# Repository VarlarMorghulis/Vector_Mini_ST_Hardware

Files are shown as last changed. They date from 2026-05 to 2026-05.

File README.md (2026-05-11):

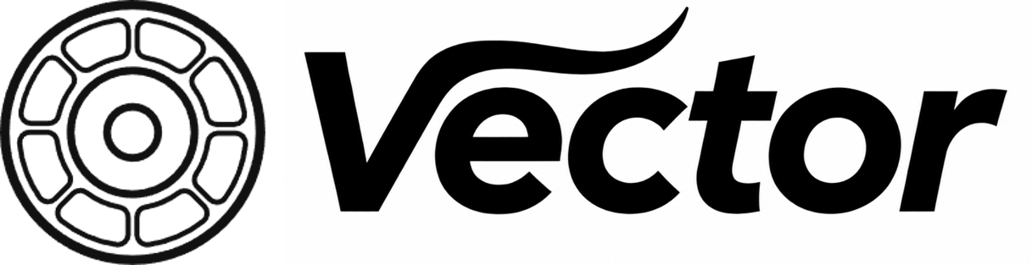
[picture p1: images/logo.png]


## 功能介绍

        Vector 驱动器是一款中小型尺寸，基于矢量控制的永磁同步电机驱动，适用于轮毂电机，关节电机等。24V母线电压下，实测最高支持约400W的持续功率输入（需散热片）。内部算法可实现基础的电流，速度，位置闭环，同时具有一定的参数辨识能力。目前仅支持有感运行，板载了一块TLE5012B绝对式编码器，同时支持外部SPI编码器信号输入。通信外设提供了USB，UART，FDCAN三种，USB和FDCAN具备自主控制协议，USB FS 波特率12Mbps，可以通过VOFA+上位机以字符串的形式向下位机发送指令，即插即用。FDCAN数据段最高波特率5Mbps，可通过外部主控向总线发送报文以实现一对多控制。驱动器具有母线过压和欠压，相线过流，过温等保护，最大程度地保障驱动能够稳定运行。

## 硬件设计

### 1.元件选型

* MCU : **STM32G431CBU6**
* 栅极驱动 : **FD6288Q**
* MOSFET : **CSD18540Q5B** 
* 采样电阻 : **2mΩ** **2512封装**
* 电流感应放大器 : **RS721XF**
* 采样方案：**三电阻低侧采样**

### 2.整体布局

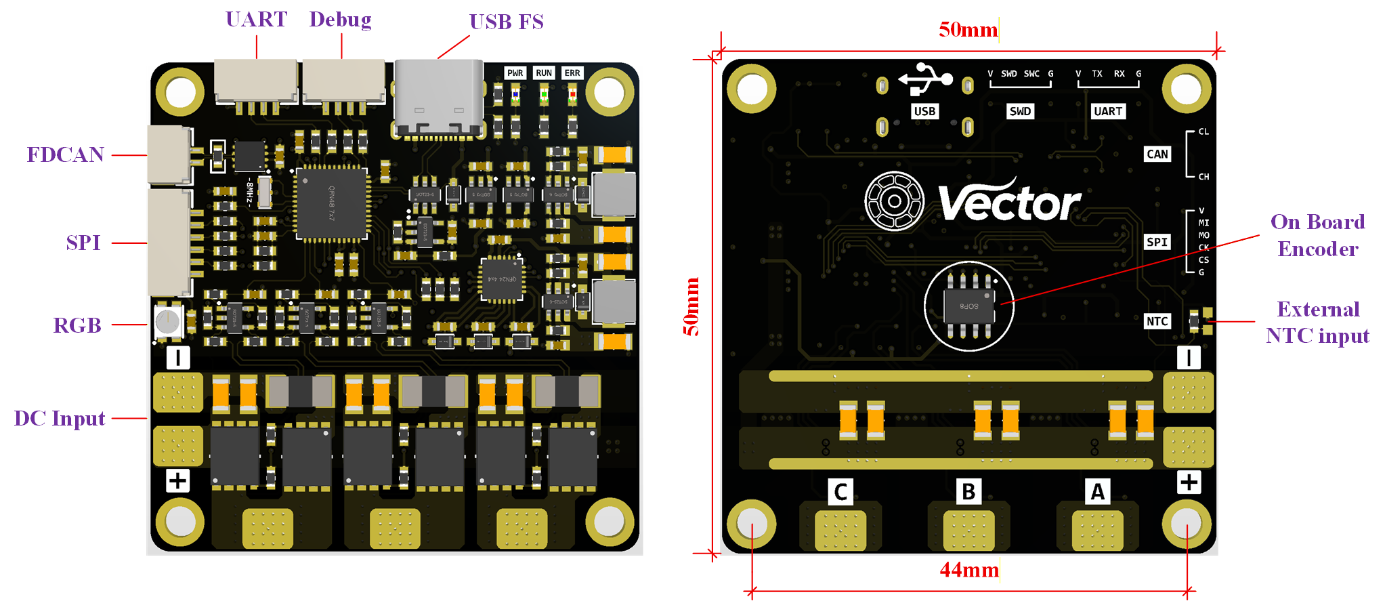
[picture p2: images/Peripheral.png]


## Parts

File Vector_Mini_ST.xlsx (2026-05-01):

Comment | Description | Designator | Footprint | LibRef | Quantity
10u/50V | 贴片电容, 1206贴片电容 | C1, C5, C22, C23, C24, C25, C26, C27, C29, C30, C31, C32, C33, C34 | C1206_S | CAP, C1206 | 14
0.1u/50V | 贴片电容, 0603贴片电容 | C2, C4, C6, C8, C11, C12, C13, C14, C17, C18, C35, C38, C40, C42 | C0603_S | CAP, C0603 | 14
22u/25V | 贴片电容 | C3, C7 | C1206_S | CAP | 2
1u/25V | 贴片电容 | C9, C10, C15, C16 | C0603_S | CAP | 4
10u/16V | 贴片电容 | C19 | C0603_S | CAP | 1
2.2u/25V | 贴片电容 | C20, C21, C28 | C0603_S | CAP | 3
1n/50V | 贴片电容 | C36, C37, C39, C41 | C0603_S | CAP | 4
GH1.25-4P |  | CN1, CN9 | GH1.25-WS-4P | GH1.25-4P | 2
GH1.25-6P |  | CN2 | GH1.25-WS-6P | GH1.25-6P | 1
PAD 5*4 |  | CN3, CN4, CN5, CN6, CN7 | PAD 5*4 | PAD 5*4 | 5
PAD 1*1 |  | CN8, CN10 | PAD 1*1 | PAD 1*1 | 2
GH1.25-2P |  | CN11 | GH1.25-WS-2P | GH1.25-2P | 1
1N5819WS | 肖特基二极管 | D1, D2, D3, D4, D5, D6 | SOD-323 | 1N5819WS | 6
USBLC6-2SC6 | USB 2.0高速接口的ESD保护 | D7 | SOT-23-6 | USBLC6-2SC6 | 1
10u/1.5A | 功率电感 | L1, L2 | SMD-0420 | IND | 2
LED-0603-B |  | LED1 | LED-0603-B | LED-0603-B | 1
LED-0603-G |  | LED2 | LED-0603-G | LED-0603-G | 1
LED-0603-R |  | LED3 | LED-0603-R | LED-0603-R | 1
WS2812B-3528 |  | LED4 | LED-3528-4P | WS2812B-3528 | 1
CSD18540Q5B |  | Q1, Q2, Q3, Q4, Q5, Q6 | VSON-8 | CSD18540Q5B | 6
470k | 贴片电阻 | R1 | R0603_S | RES | 1
69.8k | 贴片电阻 | R2 | R0603_S | RES | 1
100k | 贴片电阻 | R3, R4 | R0603_S | RES | 2
91k | 贴片电阻 | R5 | R0603_S | RES | 1
5.1k | 贴片电阻 | R6, R29, R39 | R0603_S | RES | 3
1k | 贴片电阻 | R7, R40 | R0603_S | RES | 2
2k | 贴片电阻 | R8, R19 | R0603_S | RES | 2
510R | 贴片电阻 | R9 | R0603_S | RES | 1
10k | 贴片电阻 | R10, R32 | R0603_S | RES | 2
22R | 贴片电阻 | R11, R12, R13, R14, R15, R16, R17, R18, R45, R49 | R0603_S | RES | 10
4.7R | 贴片电阻 | R20, R21, R22, R23, R24, R25 | R0603_S | RES | 6
2mR | 2512贴片电阻 | R26, R27, R28 | R2512_S | R2512 | 3
10k 0.1% | 贴片电阻 | R30, R31, R41, R42, R43, R44, R50, R51 | R0603_S | RES | 8
1k 0.1% | 贴片电阻 | R33, R34, R37, R38, R46, R48 | R0603_S | RES | 6
100R | 贴片电阻 | R35, R36, R47 | R0603_S | RES | 3
3.3k | 贴片电阻 | R52 | R0603_S | RES | 1
120R | 贴片电阻 | R53 | R0603_S | RES | 1
STM32G431CBU6 |  | U1 | QFN-48 | STM32G431CBU6 | 1
TX4137 | 60V Buck | U2, U3 | SOT-23-6 | TX4137 | 2
TLV75733PDBVR |  | U4 | SOT-23-5 | TLV75733PDBVR | 1
LP5907MFX-3.3 |  | U5 | SOT-23-5 | LP5907MFX-3.3 | 1
TLE5012BE1000 |  | U6 | SOP-8 | TLE5012BE1000 | 1
FD6288Q | 三相栅极驱动 | U7 | QFN-24 | FD6288Q | 1
RS721XF |  | U8, U9, U11, U12 | SOT-23-5 | RS721XF | 4
TJA1051TK/3/1J |  | U10 | VDFN-8 | TJA1051TK/3/1J | 1
TYPEC-WS-16P |  | USB1 | TYPEC-WS-16P | TYPEC-WS-16P | 1
8M | 无源晶振 | X1 | OSC-3213-3P | OSC-3213 | 1

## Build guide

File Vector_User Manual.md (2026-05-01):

# Vector 驱动器 用户指南

First update:2026.2

Last update:2026.5

## 一、功能介绍

        Vector 驱动器是一款中小型尺寸，基于矢量控制的永磁同步电机驱动，适用于轮毂电机，关节电机等。24V母线电压下，实测最高支持约400W的持续功率输入（需散热片）。内部算法可实现基础的电流，速度，位置闭环，同时具有一定的参数辨识能力。目前仅支持有感运行，板载了一块TLE5012B绝对式编码器，同时支持外部SPI编码器信号输入。通信外设提供了USB，UART，FDCAN三种，USB和FDCAN具备自主控制协议，USB FS 波特率12Mbps，可以通过VOFA+上位机以字符串的形式向下位机发送指令，即插即用。FDCAN数据段最高波特率5Mbps，可通过外部主控向总线发送报文以实现一对多控制。驱动器具有母线过压和欠压，相线过流，过温等保护，最大程度地保障驱动能够稳定运行。

### 1.已有功能

* 基础有感FOC算法 电流 速度 位置 可控
* 位置控制梯形速度轨迹规划
* 磁编码器偏心补偿
* 电机相电阻+dq轴电感+永磁体磁链辨识
* FDCAN通信控制+超时保护
* USB通信控制
* 支持绝对式SPI编码器 TLE5012B，MT6816, MT6701
* 过压、欠压、过流、过温保护
* 编码器断连识别

### 2.注意事项

> MCU的PB8引脚为BOOT0引脚，在设计时由于引脚紧张复用成FDCAN1_RX，让程序正常启动需要使用STM32CubeProgrammer将BOOT0软件下拉。

> 驱动供电电压为**13V-30V**，外部电源超过35V运行可能会引发器件过压损坏。

> 请按照说明完成各项参数的配置及校准，错误设置将会导致电机不正常运行。

## 二、硬件设计

### 1.元件选型

* MCU : **STM32G431CBU6**
* 栅极驱动 : **FD6288Q**
* MOSFET : **CSD18540Q5B** 
* 采样电阻 : **2mΩ** **2512封装**
* 电流感应放大器 : **RS721XF**
* 采样方案：**三电阻低侧采样**

### 2.整体布局

<center class="half">
    
</center>

<div align="center">图2-1 驱动器布局示意图

## 三、软件设置

### 1.参数定义

| 名称 | 解释 | 范围 | CAN参数ID | USB参数ID | 默认值 |
| :---: | :---: | :---: | :----: | :---: | :---: |
| mode | 运行模式 | [0,8] (int) |  0x00  |  mod  | |
|  i_set | 设定电流 | [-i_lim,i_lim] |  0x02  |  i_s  | |
| spd_set  | 设定速度 |  [-spd_lim,spd_lim]  |  0x04  |  s_s  | |
| pos_set  | 设定位置 | [-$\infty$,+$\infty$] | 0x06 | p_s |  |
| **can_id** | CAN节点ID | [0,7] (int) | 0x08 | cid | 0 |
| **pol** | 极对数 | [2,30] (int) | 0x0A | pol | 0 |
| **enc_state** | 编码器状态 | 特定值 | 0x0C | e_s | 1 |
| **i_cal** | 校准电流 | [5,30] | 0x0E | ica | 10 |
| **i_lim** | 最大电流限制 | [0,60] | 0x10 | ilm | 30 |
| **spd_lim** | 最大速度限制 | [0,400] | 0x12 | slm | 200 |
| **spd_acc** | 速度环加速度 | [0,1000] | 0x14 | sac | 50 |
| **spd_dec** | 速度环减速度 | [0,1000] | 0x16 | sde | 50 |
| **spd_kp** | 速度环比例P | [0.01,2] | 0x18 | s_p | 0.05 |
| **spd_ki** | 速度环积分I | [0,2] | 0x1A | s_i | 0.5 |
| **pos_acc** | 位置环加速度 | [0,200] | 0x1C | pac | 10 |
| **pos_dec** | 位置环减速度 | [0,200] | 0x1E | pde | 10 |
| **pos_maxspd** | 位置环最大速度 | [-spd_lim,spd_lim] | 0x20 | pms | 5 |
| **pos_kp** | 位置环比例P | [0.01,1] | 0x22 | p_p | 0.5 |
| **pos_kd** | 位置环微分D | [0,5] | 0x24 | p_d | 0.1 |
| **cogging** | 抗齿槽启用 | [0,1] (int) | 0x26 | cog | 0 |
| **can_br** | CAN波特率 | 特定值 | 0x28 | cbr |  1000  |
| **can_hb** | CAN心跳 | 0\|[500,1000] (int) | 0x2A | chb |  500 |
| vbus | 母线电压 | [12,30] | 0x2C | vbs | |
| ibus | 母线电流 | [-5,40] | 0x2E | ibs | |
| ia | A相电流 | [-i_lim,i_lim] | 0x30 | i_a | |
| ib | B相电流 | [-i_lim,i_lim] | 0x32 | i_b | |
| ic | C相电流 | [-i_lim,i_lim] | 0x34 | i_c | |
| id | 直轴电流 | [-0,+0] | 0x36 | i_d | |
| iq | 交轴电流 | [0,i_lim] | 0x38 | i_q | |
| spd1_filt | 板载编码器速度滤波值 | [-400,400] | 0x3A | s1f | |
| pos1_raw |  板载编码器位置滤波值  | [-$\infty$,+$\infty$] | 0x3C | p1f | |
| spd2_filt | 外接编码器速度滤波值 | [-400,400] | 0x3E | s2f | |
| pos2_raw | 外接编码器位置滤波值 | [-$\infty$,+$\infty$] | 0x40 | p2f | |
| temp | 驱动温度 | [-10,120] | 0x42 | tmp | |
| rs | 相电阻 | [10,500] | 0x44 | mrs | |
| ld | 直轴电感 | [1,10000] | 0x46 | mld | |
| lq | 交轴电感 | [1,10000] | 0x48 | mlq | |
| flux | 磁链 | [0.1,20] | 0x4A | mfx | |
| error | 当前错误 | [0,10] (int) | 0x4C | err | |

注释：

1.物理量单位：电压（V），电流（A），速度（r/s—转/秒），位置（r—转），加速度、减速度(r/s$^2$—转/秒$^2$)，CAN波特率（kbps），CAN心跳（ms），电阻（mΩ），电感（μH），磁链（mWb），温度（℃）。

2.0x00-0x06为**运行参数**，0x08-0x2A为**用户参数**，0x2C-0x4C为**状态参数**。

参数解释：

**运行参数**

* mode：运行模式。

  0：失能状态-电机释放 

  1：电流控制模式 

  2：速度控制模式 

  3：位置控制模式 

  4：电机参数辨识 

  5：编码器偏移及偏心补偿校准 

  6：电机齿槽转矩补偿 (暂未开放)

  7：设定位置控制零点 

  8：恢复默认配置  

  9：保存当前配置  

  10：清除当前错误。

	    电机在进入闭环控制前，需先运行模式4：电机参数辨识 。这一步的目的是获取电机的相电阻，dq轴电感和永磁体磁链，为电流环的kp ki 参数自整定提供依据。辨识现象为：第1阶段电机分别被拖拽到三处特定位置，电流线性上升；第2阶段电机发出高频声音；第3阶段电机匀加速运动，达到指定占空比后失能，辨识全程应保持**电机空载**。需要关注的用户参数为**i_cal**，设置过大可能烧坏电机，过小辨识效果差。对于电感量极低，内阻较小的电机，例如涵道电机，辨识效果较差，对于辨识结果，用户需仔细甄别。

	    若使用有感控制，需在模式4辨识成功后再运行模式5：编码器偏移及偏心补偿校准。**更换编码器型号**、**编码器重新安装**、**磁铁重新安装**、**电机线序改变**，编码器偏移均需重新校准，否则电机将无法正常运行，可能会发生跑飞的情况，校准过程中务必确保电机处于==轻载==状态。对于部分齿槽转矩较大的电机，可适当增大**校准电流**参数。

		1 2 3 为闭环控制模式，从某一种闭环控制模式切换到另一种闭环控制模式，中间需要先调用模式0，将电机失能。

		 修改用户参数后，想要实现下次上电直接使用 (掉电不丢失) ，需调用模式9进行保存。调用模式4 5 6 7 8后自动保存，无需重复调用模式9。

* i_set：设定电流，在电流控制模式下使用。
* spd_set：设定速度，机械转速，在速度控制模式下使用。
* pos_set：设定位置，在位置控制模式下使用。

------

**用户参数**

* can_id：修改当前CAN节点ID。
* pol：设置极对数，请参阅电机的参数，若电机为表贴式永磁同步电机，可通过数转子上贴装的磁钢片$\div$2的方式确认极对数，请务必确保极对数的正确，否则将无法正常闭环，严重时会烧毁电机。
* enc_state：指定编码器型号与使能状态，编码器型号有 0：TLE5012B  1：MT6816，2：MT6701，使能状态有0：关闭，1：启用。数据组合规则如下：<u>板载编码器型号+板载编码器使能状态+外接编码器型号+外接编码器状态</u>，数据为十进制。例如，板载编码器型号为TLE5012B-0，板载编码器使能状态为关闭-0，外接编码器型号为MT6816-1，外接编码器使能状态为启用-1，则enc_state的值设置为 (00)11，高位为0发送时略去。驱动enc_state默认值为 (000)1，即板载编码器TLE5012B关闭，外接编码器TLE5012B启用。
* i_cal：校准电流，一般取电机额定电流的25%-50%。
* i_lim：最大电流限制，是速度环输出的限幅值，i_lim越大，电机力矩越大。
* spd_lim：最大转速限制。
* spd_acc：电机加速度，用于速度控制模式。
* spd_dec：电机减速度，用于速度控制控制模式。acc或dec为0时，禁用速度爬升。
* spd_kp：速度环比例P。
* spd_ki：速度环积分I。

		位置环采用梯形速度轨迹规划，速度和位置曲线如图3-1所示。

* pos_acc：电机加速度，用于位置控制模式。
* pos_dec：电机减速度。用于位置控制模式。
* pos_maxspd：位置环最大速度。

Blazer-FOC

<div align="center">图3-1 梯形速度轨迹的速度及位置曲线

		速度曲线的斜率代表加速度和减速度，平台期的速度为位置环轨迹规划的最大速度。特别地，当运动路程较短时，电机来不及加速到最大速度，速度曲线将由梯形变为三角形，如图3-2所示，因此用户在使用前需预估一下行程与速度的相对关系。

Blazer-FOC

<div align="center">图3-2 梯形速度轨迹（特殊情况）的速度及位置曲线

* pos_kp：位置环比例P。

* pos_kd：位置环微分D。

* cogging：齿槽转矩补偿启用。0：禁用齿槽转矩补偿 1：启用齿槽转矩补偿。启用齿槽转矩补偿，需确保先前成功完成模式6校准。

* can_br：CAN通信波特率，当配置为<=1000kbps时，数据段和仲裁段波特率一致，当配置为>1000kbps时，数据段为设置值，仲裁段保持1000kbps不变。可选的配置值有100，125，200，250，500，1000，2000，2500，5000kbps。

* can_hb：CAN心跳超时保护时间，驱动在模式1 2 下超过设定时间没有收到CAN报文将失能电机。设置为0时，禁用此功能。

  ------

**状态参数**

* vbus：母线电压，过低或过高时，驱动进入校准和闭环将报错。
* ibus：母线电流。
* ia ib ic：A B C相电流。
* id：直轴电流，反映了电机的励磁大小。
* iq：交轴电流，反映了电机的转矩大小。
* spd1_filt：板载编码器检测速度的滤波值，机械转速。
* pos1_filt：板载编码器检测位置的滤波值，机械角度，1.0代表一圈。
* spd2_filt：外接编码器检测速度的滤波值，机械转速。
* pos2_filt：外接编码器检测位置的滤波值，机械角度，1.0代表一圈。
* temp：NTC温度，温度超过100℃将会报错。NTC放置位置反映了开关管的壳温，实际结温会高10-20℃。
* rs：电机相电阻，由模式4辨识得到。
* ld：电机直轴电感，由模式4辨识得到。
* lq：电机交轴电感，由模式4辨识得到。
* flux：电机磁链，由模式4辨识得到。
* error：当前错误。0：无错误 1：电流采样偏置错误 2：编码器错误 3：极对数错误 4：CAN断开连接 5：电阻过大 6：电感过大 7：过流 8：过压 9：欠压  10：高温。

### 2.CAN协议

		Vector驱动使用**标准帧**进行CAN通信，帧ID由节点ID和参数ID组成，格式为

                                                   **==ID段：节点ID<<8 | 参数ID  数据段：32位float==**

		<u>写操作时参数ID为偶数</u>，数据段为需要设置的参数值。<u>读操作时相应的参数ID+1，为奇数</u>，此时不关心数据段(数据段无效)。**状态参数**仅可读，写入无效。	

		例如：设置节点ID为0x02的驱动极对数为21，则ID段为 **0x20A**，数据段为**21** (float)。

				    读取节点ID为0x02的驱动内部设置的极对数，则ID段为**0x20B**，驱动回传：ID段为**0x20B**，数据段为**21** (float)。	

					读取节点ID为0x02的驱动当前母线电压，则ID段为**0x223**，驱动回传：ID段为**0x223**，数据段为**24.012**(float)。

		在实际发送数据段时，是将32位的float转变为一个uint32_t，再通过移位寄存的方式，赋给4个uint8_t，DLC长度为4个字节。注意，将float转换为uint32_t请勿使用强制类型转换，这会舍去符号和小数部分，丢失精度，以下示例是错误的：

> ```
> float current = 10.0f;
> uint32_t current_u32;
> current_u32 = (uint32_t)current;
> ```

		以下是一种正确的示例，通过将指针类型进行强制转换来重新解释内存：

> ```
> uint32_t FloatToIntBit(float x)
> {
> 	uint32_t *pInt;
> 	pInt = (uint32_t*)(&x);
> 	return *pInt;
> }
> 
> current_u32= FloatToIntBit(current);
> ```

### 3.USB协议

		Vector驱动器板载了Type C接口，可通过USB虚拟串口（VPC）与PC进行通信。分写入，读取，打印三种格式。

		<u>写入的格式如下</u>：

                                                 **==起始符+写入标志位+参数ID+数据+结束符==**

		起始符为“\”，写入标志位为“w_”，参数ID可查阅参数定义表格，数据需要满足对应参数的类型和范围，结束符为“\r\n”。

        例如：设置当前驱动的极对数为21，可使用串口助手发送“**\w_pol=21\r\n**”。

        设置当前驱动的位置环加速度为5.3，可使用串口助手发送“**\w_pac=5.3\r\n**”。

		“\r\n”对应回车和换行的ASCII码，一般在数据后加入一个空行一同发送，部分串口助手会提供追加“\r\n”结束符的选项，效果相同。

------

		<u>读取的格式如下</u>：

		 											**==起始符+读取标志位+参数ID+结束符==**

		读取标志位为“r_”，无数据段落，其他段落与写入相同。强行加入数据段落，驱动将会发送报错信息。

		例如：读取当前电机速度滤波值，可使用串口助手发送“**\r_s_f\r\n**”，在接收窗口会收到形如“spd_filt=10.5r/s”的回复。

					读取当前设置的编码器型号，可使用串口助手发送“**\r_e_t\r\n**”，在接收窗口会收到形如“enc_type=TLE5012B”的回复。

------

		打印的格式如下：

													**==起始符+打印标志位+参数ID+通道标号+结束符==**

		打印标志为“p_”，通道标号为0-4的整数，分别对应通道0-通道4。其他段落与写入相同。打印的作用在于电机运行过程中实时监看波形，如电流，速度等，最多支持同时查看的波形通道为**5条**，若新的变量通道号与之前变量通道号相同，则会覆盖先前变量。

		用于观察打印波形的上位机为<u>VOFA+</u>，数据引擎选择<u>JustFloat</u>模式，数据接口选择<u>串口</u>。

		例如：打印当前电机的直轴电流和交轴电流，可依次在VOFA+发送区输入“**\p_i_d=0\r\n**”  “**\p_i_q=1\r\n**”。效果如图3-3所示。



<div align="center">图3-3 VOFA+波形查看		

		特别地，当使能打印功能后，读取的功能将会被禁用。

## 四、参考项目

**ODRIVE**:https://github.com/odriverobotics/ODrive

**VESC**:https://github.com/vedderb/bldc

**MIT**:https://github.com/bgkatz/3phase_integrated

**AXDR**:https://oshwhub.com/lylssy/foc_driver

**dgm**:https://github.com/codenocold/dgm

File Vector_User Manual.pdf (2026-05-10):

# Vector 驱动器 用户指南

# 一、功能介绍

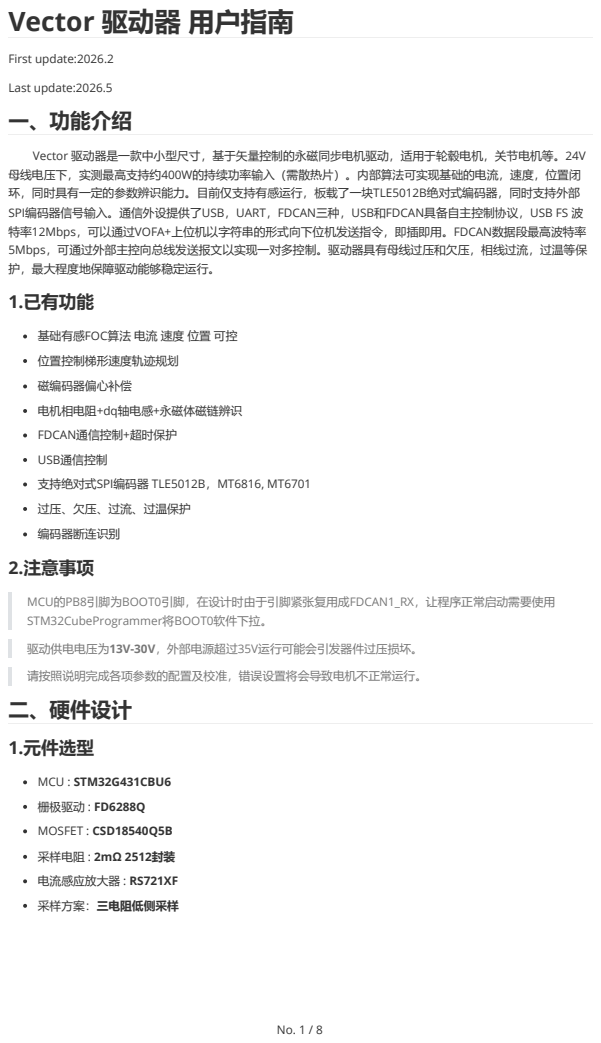
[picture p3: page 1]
First update:2026.2; Last update:2026.5; MCU的PB8引脚为BOOT0引脚，在设计时由于引脚紧张复用成FDCAN1_RX，让程序正常启动需要使用 STM32CubeProgrammer将BOOT0软件下拉。; 驱动供电电压为13V-30V，外部电源超过35V运行可能会引发器件过压损坏。; 请按照说明完成各项参数的配置及校准，错误设置将会导致电机不正常运行。 二、硬件设计; 1.元件选型; MCU : STM32G431CBU6; 栅极驱动 : FD6288Q; MOSFET : CSD18540Q5B; 采样电阻 : 2mΩ 2512封装; 电流感应放大器 : RS721XF; 采样方案：三电阻低侧采样

Vector 驱动器是一款中小型尺寸，基于矢量控制的永磁同步电机驱动，适用于轮毂电机，关节电机等。24V
母线电压下，实测最高支持约400W的持续功率输入（需散热片）。内部算法可实现基础的电流，速度，位置闭
环，同时具有一定的参数辨识能力。目前仅支持有感运行，板载了一块TLE5012B绝对式编码器，同时支持外部
SPI编码器信号输入。通信外设提供了USB，UART，FDCAN三种，USB和FDCAN具备自主控制协议，USB FS 波
特率12Mbps，可以通过VOFA+上位机以字符串的形式向下位机发送指令，即插即用。FDCAN数据段最高波特率
5Mbps，可通过外部主控向总线发送报文以实现一对多控制。驱动器具有母线过压和欠压，相线过流，过温等保
护，最大程度地保障驱动能够稳定运行。
1.已有功能

基础有感FOC算法 电流 速度 位置 可控
位置控制梯形速度轨迹规划
磁编码器偏心补偿
电机相电阻+dq轴电感+永磁体磁链辨识
FDCAN通信控制+超时保护
USB通信控制
支持绝对式SPI编码器 TLE5012B，MT6816, MT6701
过压、欠压、过流、过温保护
编码器断连识别
2.注意事项

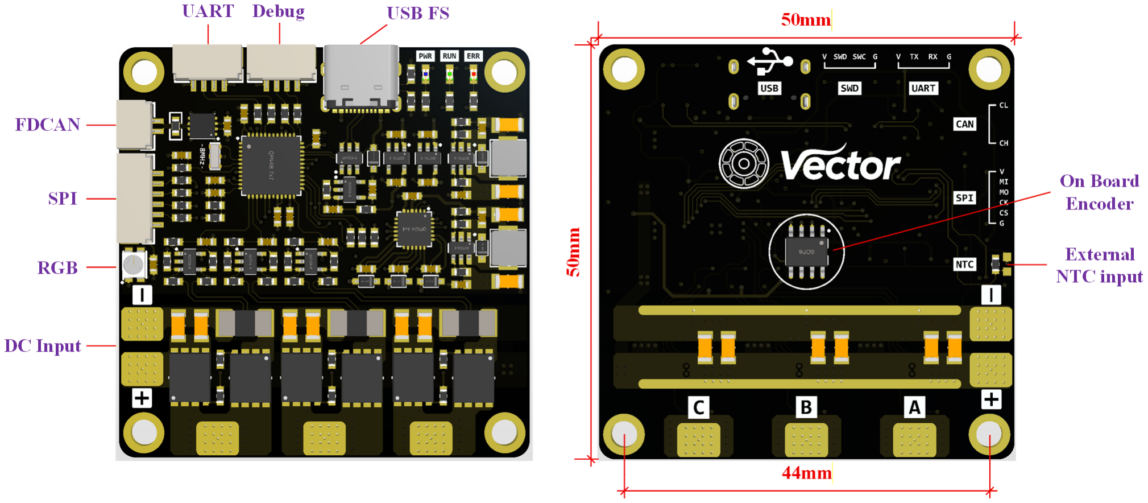
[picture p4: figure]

图2-1 驱动器布局示意图

名称 | 解释 | 范围 | CAN参数 ID | USB参数 ID | 默认 值
mode | 运行模式 | [0,10] (int) | 0x00 | mod
i_set | 设定电流 | [-i_lim,i_lim] | 0x02 | i_s
spd_set | 设定速度 | [-spd_lim,spd_lim] | 0x04 | s_s
pos_set | 设定位置 | [- ,+ ] | 0x06 | p_s
can_id | CAN节点ID | [0,7] (int) | 0x08 | cid | 0
pol | 极对数 | [2,30] (int) | 0x0A | pol | 0
enc_state | 编码器状态 | 特定值 | 0x0C | e_s | 1
i_cal | 校准电流 | [5,30] | 0x0E | ica | 10
i_lim | 最大电流限制 | [0,60] | 0x10 | ilm | 30
spd_lim | 最大速度限制 | [0,400] | 0x12 | slm | 200
spd_acc | 速度环加速度 | [0,1000] | 0x14 | sac | 50
spd_dec | 速度环减速度 | [0,1000] | 0x16 | sde | 50
spd_kp | 速度环比例P | [0.01,2] | 0x18 | s_p | 0.05
spd_ki | 速度环积分I | [0,2] | 0x1A | s_i | 0.5
pos_acc | 位置环加速度 | [0,200] | 0x1C | pac | 10
pos_dec | 位置环减速度 | [0,200] | 0x1E | pde | 10

## 2.整体布局

# 三、软件设置

## 1.参数定义

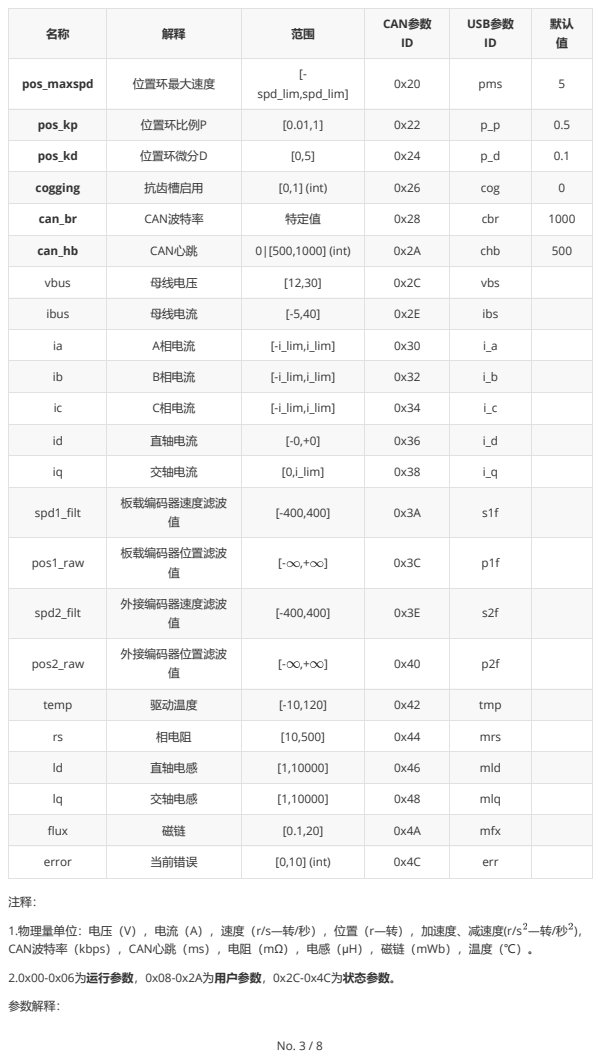
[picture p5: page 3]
参数解释：

名称 | 解释 | 范围 | CAN参数 ID | USB参数 ID | 默认 值

pos_maxspd | 位置环最大速度 | [-spd_lim,spd_lim] | 0x20 | pms | 5

pos_kp | 位置环比例P | [0.01,1] | 0x22 | p_p | 0.5

pos_kd | 位置环微分D | [0,5] | 0x24 | p_d | 0.1

cogging | 抗齿槽启用 | [0,1] (int) | 0x26 | cog | 0

can_br | CAN波特率 | 特定值 | 0x28 | cbr | 1000

can_hb | CAN心跳 | 0|[500,1000] (int) | 0x2A | chb | 500

vbus | 母线电压 | [12,30] | 0x2C | vbs

ibus | 母线电流 | [-5,40] | 0x2E | ibs

ia | A相电流 | [-i_lim,i_lim] | 0x30 | i_a

ib | B相电流 | [-i_lim,i_lim] | 0x32 | i_b

ic | C相电流 | [-i_lim,i_lim] | 0x34 | i_c

id | 直轴电流 | [-0,+0] | 0x36 | i_d

iq | 交轴电流 | [0,i_lim] | 0x38 | i_q

spd1_filt | 板载编码器速度滤波 值 | [-400,400] | 0x3A | s1f

pos1_raw | 板载编码器位置滤波 值 | [- ,+ ] | 0x3C | p1f

spd2_filt | 外接编码器速度滤波 值 | [-400,400] | 0x3E | s2f

pos2_raw | 外接编码器位置滤波 值 | [- ,+ ] | 0x40 | p2f

temp | 驱动温度 | [-10,120] | 0x42 | tmp

rs | 相电阻 | [10,500] | 0x44 | mrs

ld | 直轴电感 | [1,10000] | 0x46 | mld

lq | 交轴电感 | [1,10000] | 0x48 | mlq

flux | 磁链 | [0.1,20] | 0x4A | mfx

error | 当前错误 | [0,10] (int) | 0x4C | err

1.物理量单位：电压（V），电流（A），速度（r/s—转/秒），位置（r—转），加速度、减速度(r/s —转/秒 )，
CAN波特率（kbps），CAN心跳（ms），电阻（mΩ），电感（μH），磁链（mWb），温度（℃）。
2.0x00-0x06为运行参数，0x08-0x2A为用户参数，0x2C-0x4C为状态参数。

运行参数

mode：运行模式。
0：失能状态-电机释放
1：电流控制模式
2：速度控制模式
3：位置控制模式
4：电机参数辨识
5：编码器偏移及偏心补偿校准
6：电机齿槽转矩补偿 (暂未开放)
7：设定位置控制零点
8：恢复默认配置
9：保存当前配置
10：清除当前错误。

电机在进入闭环控制前，需先运行模式4：电机参数辨识 。这一步的目的是获取电机的相电阻，dq轴电感和 永磁体磁链，为电流环的kp ki 参数自整定提供依据。辨识现象为：第1阶段电机分别被拖拽到三处特定位置，电 流线性上升；第2阶段电机发出高频声音；第3阶段电机匀加速运动，达到指定占空比后失能，辨识全程应保持电 机空载。需要关注的用户参数为i_cal，设置过大可能烧坏电机，过小辨识效果差。对于电感量极低，内阻较小的 电机，例如涵道电机，辨识效果较差，对于辨识结果，用户需仔细甄别。

若使用有感控制，需在模式4辨识成功后再运行模式5：编码器偏移及偏心补偿校准。更换编码器型号、编码 器重新安装、磁铁重新安装、电机线序改变，编码器偏移均需重新校准，否则电机将无法正常运行，可能会发生 跑飞的情况，校准过程中务必确保电机处于轻载状态。对于部分齿槽转矩较大的电机，可适当增大校准电流参 数。

1 2 3 为闭环控制模式，从某一种闭环控制模式切换到另一种闭环控制模式，中间需要先调用模式0，将电机 失能。

修改用户参数后，想要实现下次上电直接使用 (掉电不丢失) ，需调用模式9进行保存。调用模式4 5 6 7 8后 自动保存，无需重复调用模式9。

i_set：设定电流，在电流控制模式下使用。
spd_set：设定速度，机械转速，在速度控制模式下使用。 pos_set：设定位置，在位置控制模式下使用。

用户参数

can_id：修改当前CAN节点ID。
pol：设置极对数，请参阅电机的参数，若电机为表贴式永磁同步电机，可通过数转子上贴装的磁钢片 2的 方式确认极对数，请务必确保极对数的正确，否则将无法正常闭环，严重时会烧毁电机。 enc_state：指定编码器型号与使能状态，编码器型号有 0：TLE5012B 1：MT6816，2：MT6701，使能状 态有0：关闭，1：启用。数据组合规则如下：板载编码器型号+板载编码器使能状态+外接编码器型号+外接 编码器状态，数据为十进制。例如，板载编码器型号为TLE5012B-0，板载编码器使能状态为关闭-0，外接 编码器型号为MT6816-1，外接编码器使能状态为启用-1，则enc_state的值设置为 (00)11，高位为0发送时 略去。驱动enc_state默认值为 (000)1，即板载编码器TLE5012B关闭，外接编码器TLE5012B启用。 i_cal：校准电流，一般取电机额定电流的25%-50%。 i_lim：最大电流限制，是速度环输出的限幅值，i_lim越大，电机力矩越大。 spd_lim：最大转速限制。
spd_acc：电机加速度，用于速度控制模式。
spd_dec：电机减速度，用于速度控制控制模式。acc或dec为0时，禁用速度爬升。

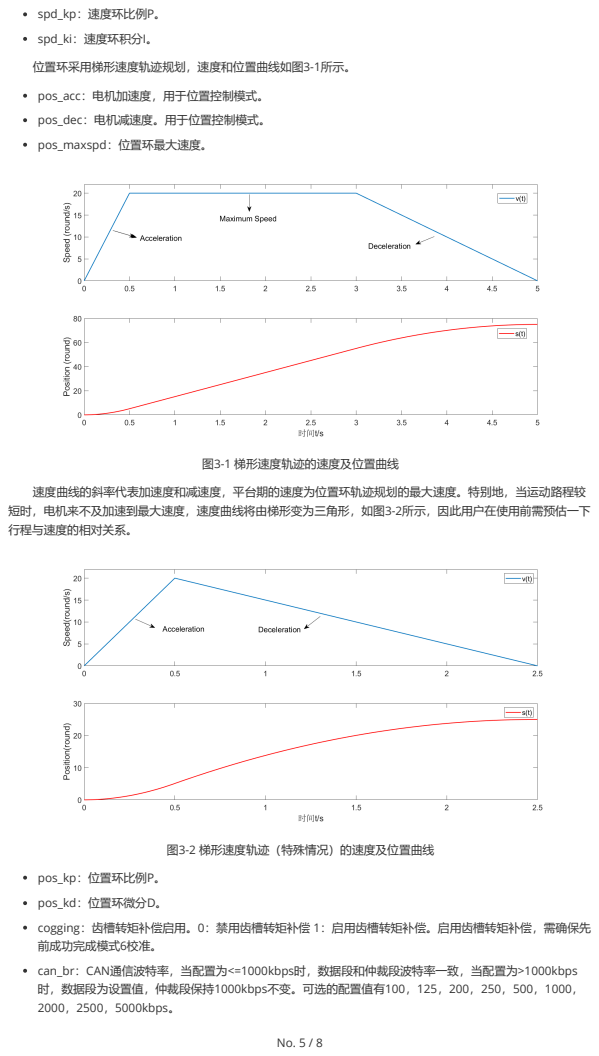
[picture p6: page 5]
图3-1 梯形速度轨迹的速度及位置曲线; spd_kp：速度环比例P。; spd_ki：速度环积分I。; 位置环采用梯形速度轨迹规划，速度和位置曲线如图3-1所示。; pos_acc：电机加速度，用于位置控制模式。; pos_dec：电机减速度。用于位置控制模式。; pos_maxspd：位置环最大速度。

速度曲线的斜率代表加速度和减速度，平台期的速度为位置环轨迹规划的最大速度。特别地，当运动路程较
短时，电机来不及加速到最大速度，速度曲线将由梯形变为三角形，如图3-2所示，因此用户在使用前需预估一下
行程与速度的相对关系。

图3-2 梯形速度轨迹（特殊情况）的速度及位置曲线

pos_kp：位置环比例P。
pos_kd：位置环微分D。
cogging：齿槽转矩补偿启用。0：禁用齿槽转矩补偿 1：启用齿槽转矩补偿。启用齿槽转矩补偿，需确保先
前成功完成模式6校准。
can_br：CAN通信波特率，当配置为<=1000kbps时，数据段和仲裁段波特率一致，当配置为>1000kbps
时，数据段为设置值，仲裁段保持1000kbps不变。可选的配置值有100，125，200，250，500，1000，
2000，2500，5000kbps。

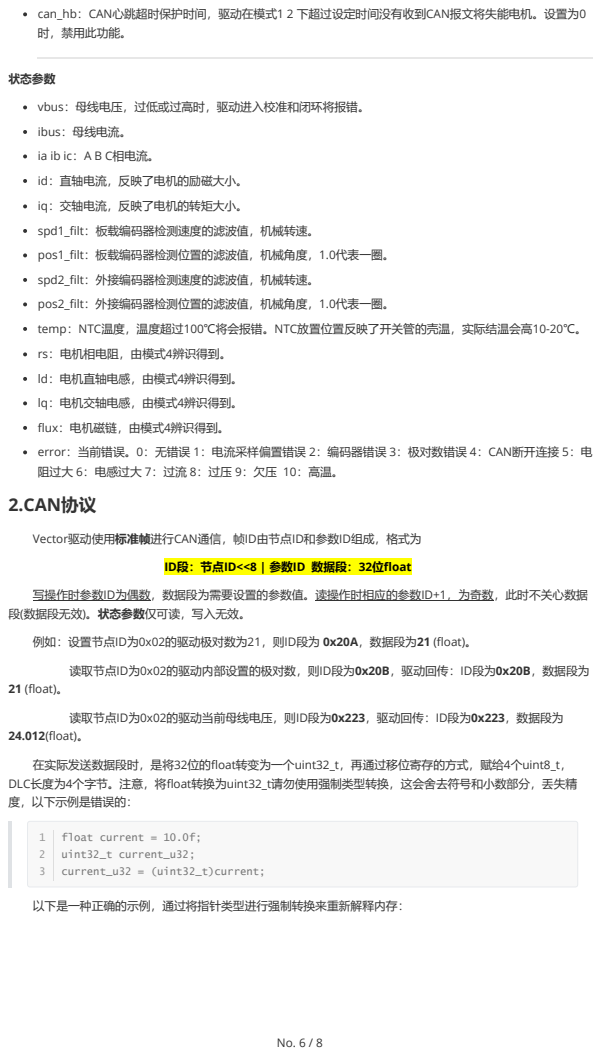
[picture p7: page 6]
can_hb：CAN心跳超时保护时间，驱动在模式1 2 下超过设定时间没有收到CAN报文将失能电机。设置为0 时，禁用此功能。; 21 (float)。; 读取节点ID为0x02的驱动当前母线电压，则ID段为0x223，驱动回传：ID段为0x223，数据段为 24.012(float)。; 以下是一种正确的示例，通过将指针类型进行强制转换来重新解释内存：; float current = 10.0f;; uint32_t current_u32;; current_u32 = (uint32_t)current;

状态参数
vbus：母线电压，过低或过高时，驱动进入校准和闭环将报错。
ibus：母线电流。
ia ib ic：A B C相电流。
id：直轴电流，反映了电机的励磁大小。
iq：交轴电流，反映了电机的转矩大小。
spd1_filt：板载编码器检测速度的滤波值，机械转速。
pos1_filt：板载编码器检测位置的滤波值，机械角度，1.0代表一圈。
spd2_filt：外接编码器检测速度的滤波值，机械转速。
pos2_filt：外接编码器检测位置的滤波值，机械角度，1.0代表一圈。
temp：NTC温度，温度超过100℃将会报错。NTC放置位置反映了开关管的壳温，实际结温会高10-20℃。
rs：电机相电阻，由模式4辨识得到。
ld：电机直轴电感，由模式4辨识得到。
lq：电机交轴电感，由模式4辨识得到。
flux：电机磁链，由模式4辨识得到。
error：当前错误。0：无错误 1：电流采样偏置错误 2：编码器错误 3：极对数错误 4：CAN断开连接 5：电
阻过大 6：电感过大 7：过流 8：过压 9：欠压 10：高温。
2.CAN协议

Vector驱动使用标准帧进行CAN通信，帧ID由节点ID和参数ID组成，格式为

ID段：节点ID<<8 | 参数ID 数据段：32位float

写操作时参数ID为偶数，数据段为需要设置的参数值。读操作时相应的参数ID+1，为奇数，此时不关心数据
段(数据段无效)。状态参数仅可读，写入无效。
例如：设置节点ID为0x02的驱动极对数为21，则ID段为 0x20A，数据段为21 (float)。
读取节点ID为0x02的驱动内部设置的极对数，则ID段为0x20B，驱动回传：ID段为0x20B，数据段为

在实际发送数据段时，是将32位的float转变为一个uint32_t，再通过移位寄存的方式，赋给4个uint8_t，
DLC长度为4个字节。注意，将float转换为uint32_t请勿使用强制类型转换，这会舍去符号和小数部分，丢失精
度，以下示例是错误的：

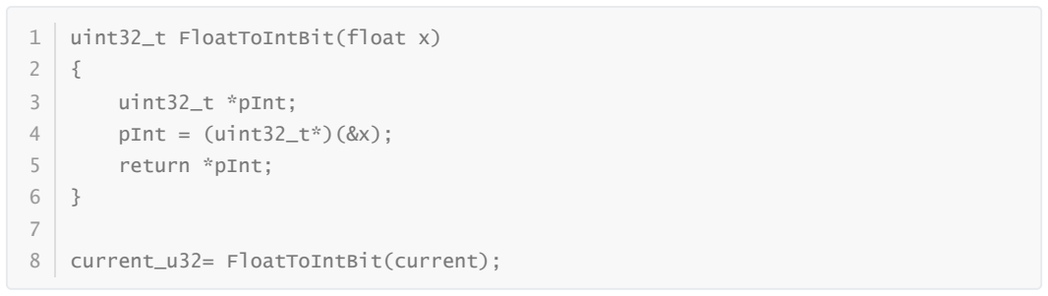
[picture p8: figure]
uint32_t FloatToIntBit(float x); uint32_t *pInt;; pInt = (uint32_t*)(&x);; return *pInt;; current_u32= FloatToIntBit(current);

## 3.USB协议

Vector驱动器板载了Type C接口，可通过USB虚拟串口（VPC）与PC进行通信。分写入，读取，打印三种格 式。

写入的格式如下：

起始符+写入标志位+参数ID+数据+结束符

起始符为“\”，写入标志位为“w_”，参数ID可查阅参数定义表格，数据需要满足对应参数的类型和范围，结束 符为“\r\n”。

例如：设置当前驱动的极对数为21，可使用串口助手发送“\w_pol=21\r\n”。

设置当前驱动的位置环加速度为5.3，可使用串口助手发送“\w_pac=5.3\r\n”。

“\r\n”对应回车和换行的ASCII码，一般在数据后加入一个空行一同发送，部分串口助手会提供追加“\r\n”结束 符的选项，效果相同。

读取的格式如下：

起始符+读取标志位+参数ID+结束符

读取标志位为“r_”，无数据段落，其他段落与写入相同。强行加入数据段落，驱动将会发送报错信息。

例如：读取当前电机速度滤波值，可使用串口助手发送“\r_s_f\r\n”，在接收窗口会收到形如 “spd_filt=10.5r/s”的回复。

读取当前设置的编码器型号，可使用串口助手发送“\r_e_t\r\n”，在接收窗口会收到形如 “enc_type=TLE5012B”的回复。

打印的格式如下：

起始符+打印标志位+参数ID+通道标号+结束符

打印标志为“p_”，通道标号为0-4的整数，分别对应通道0-通道4。其他段落与写入相同。打印的作用在于电 机运行过程中实时监看波形，如电流，速度等，最多支持同时查看的波形通道为5条，若新的变量通道号与之前变 量通道号相同，则会覆盖先前变量。

用于观察打印波形的上位机为VOFA+，数据引擎选择JustFloat模式，数据接口选择串口。 例如：打印当前电机的直轴电流和交轴电流，可依次在VOFA+发送区输入“\p_i_d=0\r\n” “\p_i_q=1\r\n”。 效果如图3-3所示。

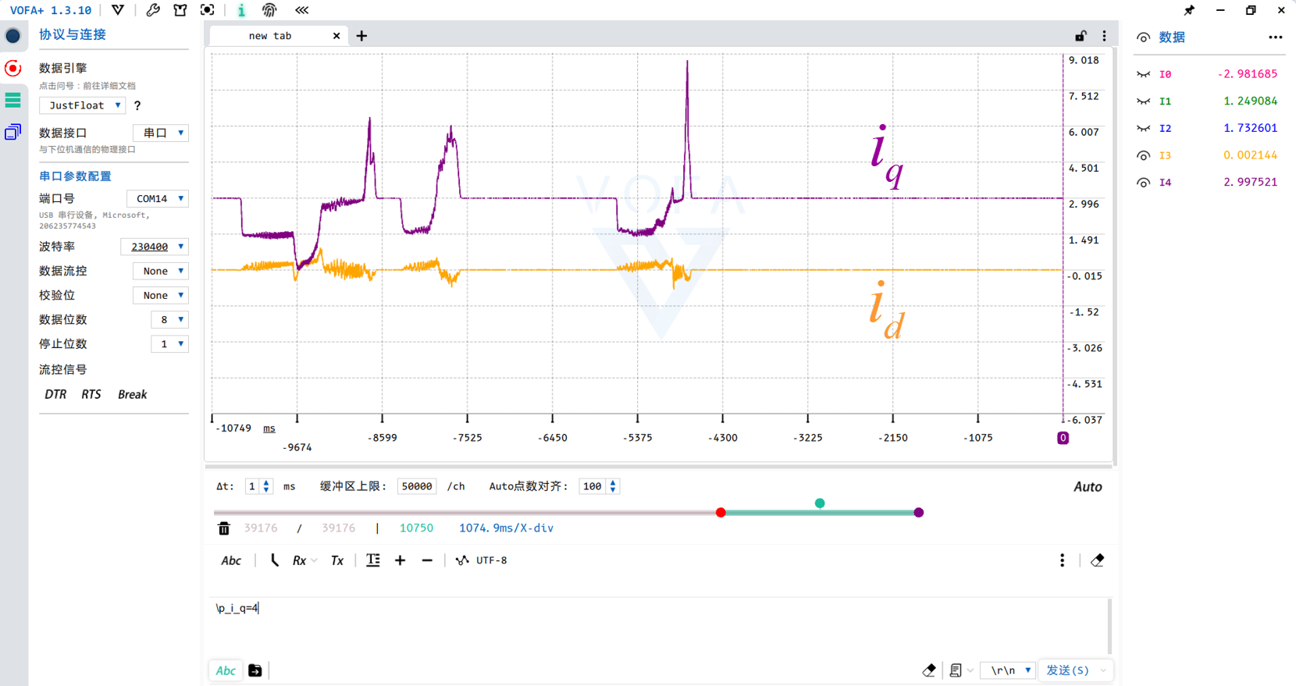
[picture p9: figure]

图3-3 VOFA+波形查看

特别地，当使能打印功能后，读取的功能将会被禁用。

# 四、参考项目

ODRIVE:https://github.com/odriverobotics/ODrive

VESC:https://github.com/vedderb/bldc

MIT:https://github.com/bgkatz/3phase_integrated

AXDR:https://oshwhub.com/lylssy/foc_driver

dgm:https://github.com/codenocold/dgm

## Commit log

2026-05-01 first update
    [Vector_Mini_ST.PcbDoc, Vector_Mini_ST.PrjPcb, Vector_Mini_ST.xlsx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]
2026-05-01 add readme
    [Vector_Mini_ST.PcbDoc]
2026-05-07 MOSFET散热优化
    对下管的D极增加了铺铜和过孔，并调整了GS驱动回路S极回流的走线
    [Vector_Mini_ST.PcbDoc]
2026-05-10 完善了网页版的readme
    [Vector_Mini_ST.PcbDoc, Vector_Mini_ST.PrjPcb]
2026-05-11 readme排版优化
    [Vector_Mini_ST.PrjPcb]
